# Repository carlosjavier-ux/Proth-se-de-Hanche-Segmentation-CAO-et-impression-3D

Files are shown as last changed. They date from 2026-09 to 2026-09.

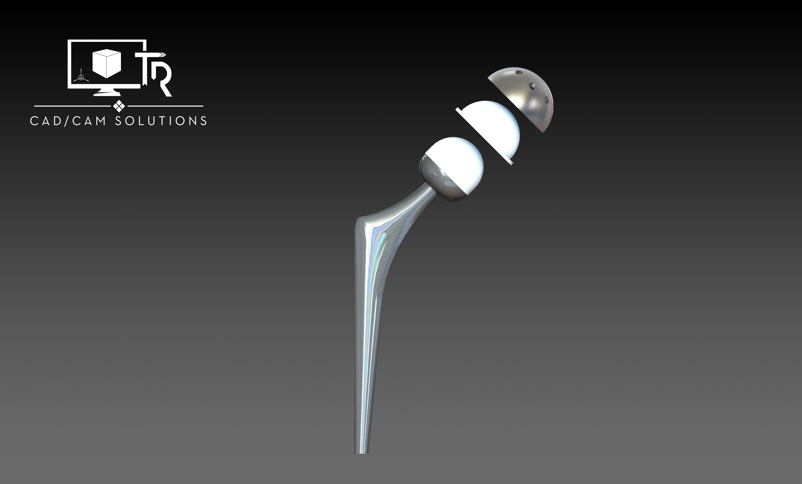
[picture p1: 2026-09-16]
Prothese_GRABCAD_NonModifie/hip1.png

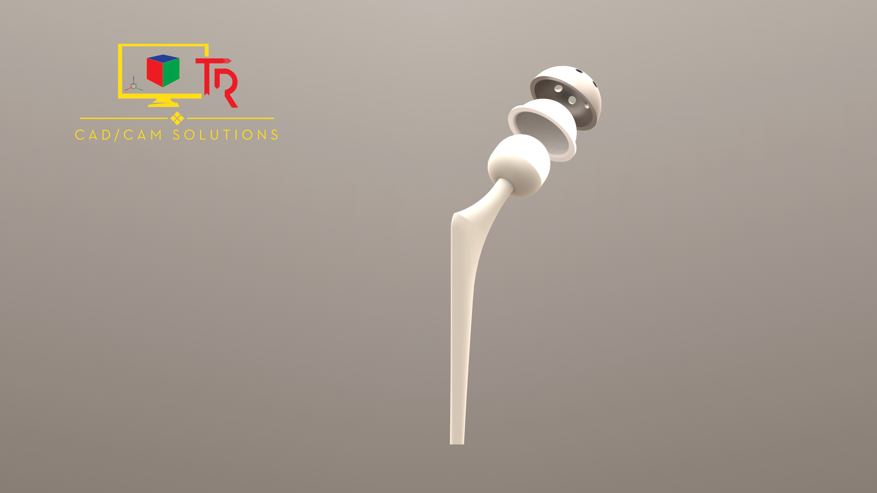
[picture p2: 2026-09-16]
Prothese_GRABCAD_NonModifie/hip.png

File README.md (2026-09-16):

# Pipeline d'Ingénierie Biomécanique : Prothèse de Hanche Personnalisée 




##  Description du Projet
Ce dépôt documente la chaîne numérique complète pour la conception et l'intégration d'une prothèse totale de hanche personnalisée, couvrant le flux de travail depuis l'acquisition anatomique jusqu'à la fabrication additive. L'objectif clinique principal de la modélisation est de restaurer le centre de rotation physiologique tout en évitant le phénomène de stress shielding, permettant de valider virtuellement l'implantation avant la production physique.

## ️ Chaîne Numérique (Pipeline Technique)

### 1. Segmentation et Traitement d'Images Médicales
L'extraction du modèle osseux fémoral à partir de l'IRM a été réalisée sous ITK-SNAP, en utilisant un processus de seuillage couplé à l'évolution d'un algorithme paramétrique Snake (Active Contours) pour garantir la précision anatomique.

### 2. Ingénierie Topologique et Nettoyage de Maillage
Le maillage brut a nécessité un post-traitement topologique intensif sous MeshLab et Meshmixer, assurant la transition vers une géométrie exploitable en CAO.
* Un algorithme de lissage de Taubin a été appliqué spécifiquement pour gommer l'effet d'escalier lié aux voxels sans altérer ni rétracter le volume global osseux, conservant ainsi les dimensions réelles.
* La structure a été optimisée par la suppression des arêtes "Non-Manifold" et une décimation quadratique réduisant le modèle à 100 000 faces, ce qui allège considérablement les calculs sans perte de détails critiques.

### 3. Simulation Biomécanique et Modélisation CAO (SolidWorks)
L'intégration du modèle d'implant (issu d'une base GrabCAD) a été paramétrée de manière biomécanique[cite: 3], en s'appuyant rigoureusement sur les centroïdes de l'anatomie native (points K, O et H).
* Ce référentiel de conception a permis de respecter strictement l'angle cervico-diaphysaire et l'offset fémoral, paramètres vitaux pour prévenir les luxations et conflits post-opératoires.
* Le lit d'implantation a été généré via des opérations booléennes avancées, notamment par une soustraction volumique (fonction Empreinte) et un enlèvement de matière balayé pour modéliser le tunnel exact d'insertion chirurgicale, validant virtuellement le passage physique de la tige fémorale.

### 4. Fabrication Additive (Impression 3D)
La validation physique de l'assemblage complet a été matérialisée grâce à une imprimante Bambu Lab, offrant une tolérance dimensionnelle optimale.
* Les modèles, incluant le fémur évidé et la prothèse préalablement scindée en deux parties pour éviter les surplombs complexes, ont été préparés pour garantir l'intégrité absolue des surfaces de contact, démontrant la viabilité de l'ensemble de la chaîne d'impression.

## Architecture du Dépôt

```text
├── FichiersSolidWorks/              # Assemblages (.sldasm) et pièces paramétriques (.sldprt) intégrant les coupes booléennes
├── FichiersEnSTL/                   # Maillages optimisés prêts pour le tranchage et l'impression 3D
├── Prothese_GRABCAD_NonModifie/     # Modèles CAO d'origine de l'implant avant adaptation biomécanique
└── IRM+Segmentation-Femur_1/        # Données sources isolées (fichiers .nii exclus du versioning pour optimisation)

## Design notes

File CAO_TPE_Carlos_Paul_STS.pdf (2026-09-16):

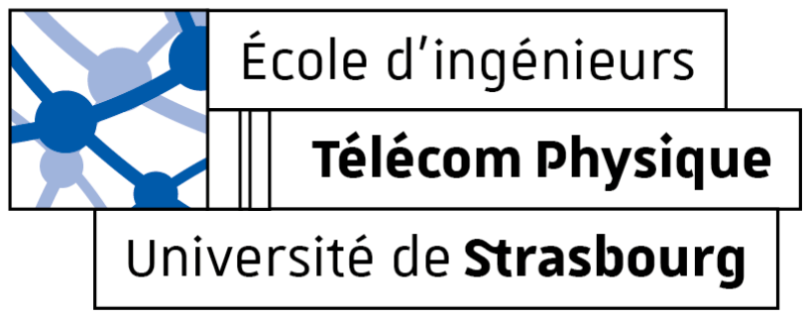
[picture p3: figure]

2025-26

# TPE STS

## Protocoles CAO

Carlos ALVAYERO VALIENTE
Paul GUIDONI-TARISSI

2A - Généraliste - STS

Ce document décrit le protocole complet, de la segmentation d'une acquisition IRM à l'impression 3D, intégrant les altérations anatomiques induites par l'implantation d'une prothèse.

Il regroupe donc les protocoles des logiciels suivants :

- ITK-SNAP
- MeshLab
- Meshmixer
- SolidWorks
©2026 Paul GUIDONI-TARISSI et Carlos ALVAYERO VALIENTE. Tous droits réservés. | 2

# ITK-SNAP

1. Préparation et Importation
- Ouvrez votre fichier IRM : File -> Open Main Image.
- Assurez-vous que le contraste est optimal pour distinguer l'os cortical (généralement noir en IRM) de la moelle et des tissus mous environnants.
2. Configuration de l'outil Snake
1. Sélectionnez l'outil Snake Tool dans la barre d'outils à gauche (icône ressemblant à un serpent ou une bulle).
2. Définissez la zone de travail (ROI) : Une boîte rouge apparaît. Ajustez-la dans les trois vues (axiale, sagittale, coronale) pour qu'elle englobe uniquement le fémur. Cela limite les calculs et évite que la segmentation ne "fuit" vers d'autres os.
3. Cliquez sur Segment 3D en bas à droite.
3. Étape de Prétraitement (Pre-segmentation)

C'est ici que vous déterminez ce qui la zone d’intéret et ce qui ne l'est pas.

- Mode de prétraitement : Choisissez généralement Thresholding (Seuillage).
- Réglage des seuils : En IRM, l'os compact est sombre, mais l'intérieur (moelle) peut être clair. Vous devez ajuster les curseurs pour que le fémur apparaisse en blanc (fortes probabilités) et le reste en bleu/transparent.
- Note : Si l'os est plus sombre que les tissus, utilisez un seuil inversé ou le mode "Edge-based" (basé sur les contours) si les contrastes sont nets.
- Cliquez sur Next.
4. Initialisation des "Bulles"
- Vous devez maintenant placer des germes (seeds). Cliquez sur le fémur dans les différentes vues pour placer des petites bulles rouges.
- Placez-en plusieurs le long de la diaphyse et au niveau de la tête fémorale.
- Ces bulles vont "gonfler" pour remplir l'espace défini lors de l'étape précédente.
5. Évolution du Snake
- Dans l'onglet Evolution, ajustez les paramètres si nécessaire :
- Continuity force : Empêche le serpent de devenir trop irrégulier.
- Balloon force : Pousse les bulles à se dilater.
- Cliquez sur le bouton Play (flèche droite). Vous verrez les bulles s'étendre automatiquement pour épouser les formes de l'os.
©2026 Paul GUIDONI-TARISSI et Carlos ALVAYERO VALIENTE. Tous droits réservés. | 3

- Arrêtez l'évolution (Pause) avant que la segmentation ne dépasse les limites de l'os (phénomène de "fuite").
6. Finalisation et Retouches
- Une fois satisfait, cliquez sur Update pour transformer l'évolution en un label solide.
- Nettoyage manuel : Utilisez l'outil Adaptive Brush (Pinceau) pour corriger les petites erreurs, notamment au niveau des articulations où le logiciel peut confondre le fémur avec le tibia ou le bassin.
©2026 Paul GUIDONI-TARISSI et Carlos ALVAYERO VALIENTE. Tous droits réservés. | 4

# MeshLab

1. Importer le modèle

Ouvrez MeshLab et glissez-déposez le fichier .stl que vous avez exporté depuis ITK-SNAP.

### 2. Nettoyer les "bruits" flottants très fréquents en IRM

La segmentation attrape souvent des petits pixels isolés qui flottent autour de l'organe principal. Il faut les supprimer avant de lisser.

1. Allez dans le menu Filters > Cleaning and Repairing.
2. Cliquez sur Remove Isolated pieces (wrt Diameter).
3. Dans la fenêtre, le paramètre Max Diameter détermine la taille maximale des morceaux à supprimer. Laissez par défaut ou augmentez légèrement, cochez Remove unreferenced vertices, puis cliquez sur Apply.
4. Fermez la fenêtre. Tous les petits fragments flottants ont disparu.

### 3. Le Lissage (Gommer l'effet "escalier" des voxels)

C'est l'étape magique pour les fichiers médicaux. Nous allons utiliser un filtre spécifique qui lisse la surface sans pour autant faire rétrécir (dégonfler) votre modèle.

1. Allez dans Filters > Smoothing, Fairing and Deformation.
2. Sélectionnez Taubin Smooth (c'est le meilleur algorithme pour les données médicales).
3. Une fenêtre s'ouvre. Le paramètre important est Smoothing steps (Nombre d'étapes de lissage).
- Par défaut, il est sur 10. Changez-le pour 50 ou 100 pour commencer.
- J’ai changé de lambda pour 0.75 (dans mon cas d’un fémur).
4. Cliquez sur Apply. Observez votre modèle : il devrait perdre son aspect “escalier” pour devenir organique et lisse. S'il n'est pas assez lisse, cliquez sur Apply ou augmentez le nombre d'étapes.

### 4. Boucher les petits trous (Étanchéité)

Le lissage peut parfois révéler ou étirer de minuscules trous dans le maillage.

1. Allez dans Filters > Remeshing, Simplification and Reconstruction.
2. Sélectionnez Close Holes.
3. Dans Max size to be closed, laissez par défaut (cela bouchera les petits trous sans détruire la forme globale) et cliquez sur Apply.
©2026 Paul GUIDONI-TARISSI et Carlos ALVAYERO VALIENTE. Tous droits réservés. | 5

Si il y a une erreur :

Étape 4.1 : Supprimer les faces "Non-Manifold"

Nous allons demander au logiciel de détruire la géométrie impossible.

1. Allez dans le menu Filters > Cleaning and Repairing.
2. Cliquez sur Remove Faces from Non Manifold Edges.
3. Dans la petite fenêtre qui s'ouvre, cliquez sur Apply puis fermez-la. Note : Cette action va supprimer les mauvais triangles. Cela va potentiellement agrandir certains trous ou en créer de nouveaux, mais c'est exactement ce que l'on veut : obtenir des trous propres.

Étape 4.2 : (Recommandé) Gérer les faces croisées

Souvent, les problèmes non-manifold sont accompagnés de faces qui rentrent les unes dans les autres.

1. Allez dans Filters > Cleaning and Repairing.
2. Cliquez sur Select Self Intersecting Faces (Sélectionner les faces qui s'auto-intersectent), puis sur Apply et fermez.
3. Si certaines zones de votre modèle deviennent rouges, ce sont les faces corrompues.
4. Pour les supprimer, regardez dans la barre d'icônes tout en haut de MeshLab. Cherchez l'icône représentant un triangle jaune avec une petite croix rouge (le bouton s'appelle "Delete the current set of selected faces" si vous laissez la souris dessus). Cliquez dessus.

Étape 4.3 : Relancer le bouchage de trous

Maintenant que les bords de vos trous sont propres et "manifold", l'outil va fonctionner.

1. Allez dans Filters > Remeshing, Simplification and Reconstruction.
2. Sélectionnez Close Holes.
3. Cliquez sur Apply.

### 5. La Décimation (Alléger le fichier)

Les modèles segmentés par IRM font souvent des millions de triangles. Si vous l'envoyez tel quel dans un logiciel de tranchage d'impression 3D, votre ordinateur risque de planter. Il faut le compresser.

1. Allez dans Filters > Remeshing, Simplification and Reconstruction.
2. Cliquez sur Simplification: Quadric Edge Collapse Decimation.
©2026 Paul GUIDONI-TARISSI et Carlos ALVAYERO VALIENTE. Tous droits réservés. | 6

3. Repérez la ligne Target number of faces (Nombre de faces cible).
- Remplacez le chiffre par 100000 (100 000 triangles) ou 50000. C'est un excellent compromis entre qualité des détails et légèreté du fichier.
4. Assurez-vous que les cases Preserve Boundary of the mesh et Preserve Normal sont cochées.
5. Cliquez sur Apply. L'opération peut prendre quelques dizaines de secondes selon la puissance de votre ordinateur.

### 6. Exporter le résultat final

Votre modèle est maintenant lisse, propre et léger.

1. Allez dans File > Export Mesh As...
2. Nommez votre fichier (par exemple Modele_IRM_Lisse.stl).
3. Dans la fenêtre des paramètres d'exportation, décochez "Color" et assurez-vous de choisir le format Binary.
4. Cliquez sur OK.
©2026 Paul GUIDONI-TARISSI et Carlos ALVAYERO VALIENTE. Tous droits réservés. | 7

# Meshmixer

Méthode pour reboucher les trous pour fermer le contour

Le logiciel va détecter le trou béant et le refermer :

1. Importez votre fichier STL dans Meshmixer.
2. Dans le menu de gauche, cliquez sur Analysis, puis sur Inspector.
3. Meshmixer va analyser le modèle. Le grand trou à la base de votre os sera désigné par une sphère (ou une bulle) de couleur, généralement bleue ou magenta, reliée par un trait au bord du trou.
4. Attention : Avant de cliquer sur cette bulle, regardez le petit menu en haut à gauche. Cherchez la ligne Hole Fill Mode (Mode de remplissage). Par défaut, il est sur Flat Fill (Remplissage plat). Pour un os, changez-le en Smooth Fill (Remplissage lisse). Cela permettra à la matière de s'arrondir naturellement au lieu de faire une coupe parfaitement plate.
5. Cliquez sur la petite bulle colorée qui pointe vers votre trou. Le trou va se boucher.
6. Cliquez sur Done en haut à gauche pour valider.

Couper un objet en deux

Étape 1 : Activer l'outil de coupe

1. Importez votre fichier STL dans Meshmixer.
2. Dans le menu principal à gauche, cliquez sur Edit.
3. Cliquez sur l'outil Plane Cut (Coupe par plan).

Étape 2 : Positionner la coupe

Un grand plan transparent quadrillé apparaît à travers votre objet, accompagné d'un manipulateur au centre (des flèches et des arcs de cercle).

- Cliquez et tirez sur les flèches pour déplacer le plan de haut en bas ou de gauche à droite.
- Cliquez et tirez sur les arcs de cercle pour incliner le plan.
- Astuce : Si vous voulez une rotation parfaite (par exemple exactement 90°), maintenez la touche Maj (Shift) enfoncée pendant que vous tournez l'arc de cercle, cela va cranter la rotation par paliers.
©2026 Paul GUIDONI-TARISSI et Carlos ALVAYERO VALIENTE. Tous droits réservés. | 8

Étape 3 : Le réglage crucial (Garder les deux moitiés)

Attention : Par défaut, Meshmixer va supprimer l'une des deux moitiés (la partie transparente). Si vous voulez garder les deux morceaux, il faut changer un réglage :

1. Regardez la petite fenêtre d'options "Plane Cut" en haut à gauche.
2. Cherchez la ligne Cut Type (Type de coupe). Par défaut, il est sur Cut (Discard Half).
3. Cliquez dessus et changez-le pour Slice (Keep Both). Votre objet redevient entièrement opaque, avec une ligne rouge au milieu.
4. Juste en dessous, assurez-vous que le Fill Type (Type de remplissage) est sur Remeshed Fill. Cela permet à Meshmixer de boucher les trous créés par la coupe pour que les deux morceaux soient bien étanches.
5. Cliquez sur Accept.

Étape 4 : Séparer les deux morceaux

La pièce est maintenant coupée et rebouchée, mais pour le moment, Meshmixer considère toujours qu'il s'agit d'un seul et unique fichier contenant deux morceaux collés. Il faut les séparer.

1. Retournez dans le menu Edit à gauche.
2. Cliquez sur Separate Shells (Séparer les coques).
3. Une petite fenêtre flottante appelée Object Browser apparaît. Vous y verrez maintenant deux lignes (vos deux morceaux), au lieu d'une seule.

Étape 5 : Exporter chaque morceau

Pour imprimer vos pièces, il faut les exporter en deux fichiers STL distincts.

1. Dans la fenêtre Object Browser, cliquez sur le premier morceau (il va se mettre en surbrillance blanche dans la zone 3D). L'autre morceau va devenir grisé ou invisible, c'est normal avec l'icône de l'œil.
2. Allez dans File > Export.
3. Choisissez le format STL Binary Format et nommez-le.
4. Retournez dans l'Object Browser, cliquez sur le deuxième morceau et répétez l'opération File > Export.
©2026 Paul GUIDONI-TARISSI et Carlos ALVAYERO VALIENTE. Tous droits réservés. | 9

# SolidWork

Ouvrir un fichier .stl :

Dans SolidWorks, aller dans ouvrir en haut à gauche, en sélectionnant le fichier aller dans option et cocher corps volumique, dans importer en tant que.

Méthode : dans un fichier Assemblage (.sldasm)

1. Éditer la pièce cible : Dans l'arbre de création à gauche, cliquez sur le nom de votre Fémur et sélectionnez Éditer la pièce (l'icône avec une petite page et un crayon bleu).
2. Lancer l'outil : Allez dans le menu tout en haut : Insertion > Fonctions de moule > Empreinte (Cavity).
3. Sélectionner l'outil de coupe : Dans le menu de gauche qui vient de s'ouvrir, cliquez dans la case bleue "Composants de conception", puis cliquez sur votre Prothèse dans la zone graphique 3D.
4. Valider : Cliquez sur la coche verte.
5. Quitter l'édition : Cliquez sur le bouton de confirmation d'édition (la petite icône bleue en haut à droite de la zone graphique) pour repasser en mode Assemblage normal.
6. Vérification : Si vous cachez la prothèse (clic droit > Cacher), vous verrez que votre fémur est maintenant parfaitement évidé avec la forme exacte de l'insert.

Méthode : Prévoir insertion, exemple prothèse fémur

Étape 1 : Dessiner la trajectoire de sortie/entrée

Le logiciel a besoin d'une ligne droite pour savoir dans quelle direction et sur quelle distance vous allez tirer la prothèse pour la sortir du fémur.

1. Ouvrez votre fichier fémur (assurez-vous d'avoir la prothèse et le fémur dans le même fichier .sldprt sous forme de "Corps volumiques", ou soyez en mode "Éditer la pièce" dans votre assemblage avec la prothèse visible).
2. Sélectionnez un plan (Face ou Droite) qui traverse le milieu de votre fémur et de la prothèse.
3. Cliquez sur Esquisse.
4. Dessinez une simple Ligne droite. Faites-la partir du centre de la prothèse et pointer vers l'extérieur (vers le haut, dans l'axe d'extraction naturel que le chirurgien utiliserait).
5. Assurez-vous que la ligne soit assez longue pour que la prothèse sorte complètement de l'os.
6. Validez et quittez l'esquisse.
©2026 Paul GUIDONI-TARISSI et Carlos ALVAYERO VALIENTE. Tous droits réservés. | 10

Étape 2 : Le balayage volumique (Le "tunnel" d'insertion)

On va utiliser la prothèse comme un outil qu'on va tirer le long de la ligne.

1. Allez dans l'onglet Fonctions et cliquez sur Enlèvement de matière balayé (l'icône avec un tuyau coupé).
2. Dans le menu de gauche, cochez impérativement l'option Profil de corps volumique (Solid Profile) au lieu de "Profil d'esquisse".
3. Dans la case bleue (Corps d'outil), cliquez sur votre Prothèse.
4. Dans la case rose (Trajectoire), cliquez sur la Ligne droite que vous venez de dessiner.
5. Regardez l'aperçu jaune : SolidWorks va vous montrer le "tunnel" généré par le mouvement de la prothèse.
6. Cliquez sur la coche verte pour valider.
©2026 Paul GUIDONI-TARISSI et Carlos ALVAYERO VALIENTE. Tous droits réservés. | 11

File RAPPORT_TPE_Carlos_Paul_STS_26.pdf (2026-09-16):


2025-26

# TPE STS

## Prothèse de Hanche : Segmentation, CAO et impression 3D

Carlos ALVAYERO VALIENTE
Paul GUIDONI-TARISSI

2A - Généraliste - STS

# Table des matières

### 2. Acquisition et Traitement du Modèle Anatomique (Workflow Numérique)4

2.2. Nettoyage et Optimisation du Maillage (MeshLab et Meshmixer).....4
©2026 Paul GUIDONI-TARISSI et Carlos ALVAYERO VALIENTE. Tous droits réservés. | 2

## Introduction

L’arthroplastie totale de hanche (PTH) est l’une des interventions chirurgicales les plus pratiquées pour traiter des pathologies invalidantes telles que la coxarthrose ou l’ostéonécrose aseptique. Toutefois, la réussite clinique dépend d'un compromis complexe entre la géométrie de la prothèse et la précision de l'acte chirurgical. L'émergence de la chaîne numérique permet aujourd'hui une personnalisation sans précédent.

L'objectif de ce projet est de simuler l'intégralité du processus de conception d'un segment anatomique : de l'acquisition des données anatomiques par IRM à la réalisation d'un prototype physique par impression 3D. À travers l'étude d'un modèle de fémur, nous détaillons les étapes de segmentation d'images, de nettoyage de maillage, de positionnement biomécanique en CAO, et enfin d'opérations booléennes permettant de simuler l'implantation chirurgicale.

©2026 Paul GUIDONI-TARISSI et Carlos ALVAYERO VALIENTE. Tous droits réservés. | 3

## 1. Contexte Clinique et Justification Biomécanique

La conception d'une prothèse repose sur des impératifs de transfert de charges dictés par la pathologie du patient. L'intervention vise à pallier des défaillances telles que la coxarthrose (usure du cartilage représentant 80 % des indications) ou l'ostéonécrose aseptique (effondrement structurel de l'os par ischémie).

Pour répondre à ces contraintes, l'implant fémoral (tige) doit assurer une stabilité rotationnelle et éviter le phénomène de stress shielding (absorption excessive des contraintes par l'implant, menant à l'atrophie osseuse). Le défi de notre modélisation est donc d'intégrer virtuellement une prothèse tout en respectant l'anatomie native du patient.

Pour une analyse approfondie des données cliniques, chirurgicales et des sources consultées, il convient de se référer au document de bibliographie joint à ce projet.

©2026 Paul GUIDONI-TARISSI et Carlos ALVAYERO VALIENTE. Tous droits réservés. | 4

## 2. Acquisition et Traitement du Modèle Anatomique (Workflow Numérique)

La première phase de notre chaîne numérique consiste à extraire un modèle 3D exploitable à partir de données d'imagerie médicale brutes.

### 2.1. Segmentation des données IRM

Nous nous sommes basés sur une banque d'images IRM (IRM-Femur_1 ) fournie par M. Baptiste Gomes. La segmentation a été réalisée sous le logiciel ITK-SNAP pour isoler le tissu osseux fémoral des tissus mous environnants, générant ainsi un premier maillage de surface (fichier Carlos&Paul.nii ) exporté au format STL.

### 2.2. Nettoyage et Optimisation du Maillage (MeshLab et Meshmixer)

Le maillage brut issu de l'IRM présentait un effet "escalier" (lié à la taille des voxels) et de nombreux artefacts géométriques, le rendant inexploitable pour des opérations CAO ultérieures. Un post-traitement rigoureux a été appliqué sous MeshLab et Meshmixer :

- Suppression du bruit et réparation : Élimination des "bruits" flottants (fragments isolés) via le filtre de nettoyage de MeshLab. Les faces "Non-Manifold" et les auto-intersections ont été supprimées pour garantir l'intégrité topologique du modèle.
- Lissage de surface (Smoothing) : Application de l'algorithme Taubin Smooth (avec 50 à 100 étapes et un λ de 0.75). Cet algorithme spécifique aux données médicales permet de lisser la surface sans provoquer de rétractation (rétrécissement) du volume global.
- Rebouchage et Étanchéité : Les trous générés par la coupe des extrémités ont été rebouchés sous Meshmixer en utilisant l'option Smooth Fill, permettant de conserver une courbure organique.
- Décimation : Pour permettre la manipulation sous SolidWorks, le maillage a été compressé à environ 100 000 faces via l'outil Quadric Edge Collapse Decimation, tout en préservant les normales et les frontières géométriques.
©2026 Paul GUIDONI-TARISSI et Carlos ALVAYERO VALIENTE. Tous droits réservés. | 5

## 3. Positionnement Virtuel et Opérations de CAO (SolidWorks)

Un modèle 3D de prothèse de hanche a été sourcé (GrabCad) puis importé dans l'environnement d'assemblage de SolidWorks aux côtés du fémur optimisé.

### 3.1. Référentiel et Positionnement Biomécanique

Le placement de l'implant ne se fait pas arbitrairement. Nous nous sommes appuyés sur les règles géométriques définies dans la thèse d'Anthony Viste. L'orientation fémorale a été construite autour de trois points centroïdes critiques :

- Le point K (centre du genou).
- Le point O (centre de la base du col fémoral).
- Le point H (centre de la tête fémorale).

L'alignement de la tige et du col a nécessité le respect de l'angle cervico-diaphysaire natif (ACD) et de l'offset fémoral. La prothèse a été orientée de manière à simuler le rétablissement du centre de rotation (COR) physiologique pour prévenir tout conflit mécanique post-opératoire.

### 3.2. Opérations Booléennes et Simulation d'Implantation

Une fois le positionnement validé, il a fallu évider le fémur pour modéliser le lit d'implantation. Nous avons procédé en deux étapes sous SolidWorks :

1. L'Empreinte (Opération booléenne statique) : Utilisation de la fonction "Empreinte" (Cavity) en mode assemblage pour soustraire le volume exact de la tige fémorale du corps volumique du fémur.
2. Le chemin d'insertion (Balayage cinématique) : Lors de la chirurgie, la prothèse n'apparaît pas par magie dans l'os ; elle y est insérée. Nous avons modélisé ce "tunnel" d'insertion en dessinant une esquisse de la trajectoire d'extraction (alignée sur l'axe du canal médullaire). Un "Enlèvement de matière balayé" utilisant le corps volumique de la prothèse comme outil de coupe a ensuite été réalisé.
©2026 Paul GUIDONI-TARISSI et Carlos ALVAYERO VALIENTE. Tous droits réservés. | 6

## 4. Préparation à la Fabrication Additive (Impression 3D)

La dernière phase du projet a consisté à générer les fichiers finaux pour la concrétisation physique. L’impression des différents composants a été réalisée sur une machine Bambu Lab, choisie pour sa haute précision dimensionnelle et sa gestion optimisée des supports, garantissant le respect des tolérances géométriques de l'assemblage. Les modèles ont été scindés ou adaptés pour optimiser la qualité d'impression. L'arborescence des livrables finaux se décline ainsi :

- FemurCoupeEvide_FINAL_imp : Le fémur imprimé, coupé au niveau du col, présentant le canal d'insertion modélisé.
- TeteFemorale_FINAL_imp : La tête fémorale native, correspondant à la résection osseuse effectuée par le chirurgien.
- ProtheseEntiere_FINAL : Imprimée en deux parties (PART1 et PART2) pour éviter les surplombs complexes et garantir l'intégrité des surfaces d'assemblage.
- Les | composants | acétabulaires | : | Acetabular_FINAL_imp (cupule) | et
PlasticLiner_FINAL_imp (insert).
©2026 Paul GUIDONI-TARISSI et Carlos ALVAYERO VALIENTE. Tous droits réservés. | 7

## Conclusion

Ce projet transversal nous a permis d'appréhender la complexité du développement d'implants orthopédiques. En maîtrisant la transition entre l'imagerie médicale (ITK-SNAP), la réparation topologique (MeshLab/Meshmixer) et la conception mécanique paramétrique (SolidWorks), nous avons validé une méthodologie robuste de positionnement virtuel. Cette chaîne numérique, conclue par l'impression 3D des composants, illustre comment l'ingénierie moderne répond aux défis cliniques de la chirurgie personnalisée.

©2026 Paul GUIDONI-TARISSI et Carlos ALVAYERO VALIENTE. Tous droits réservés. | 8

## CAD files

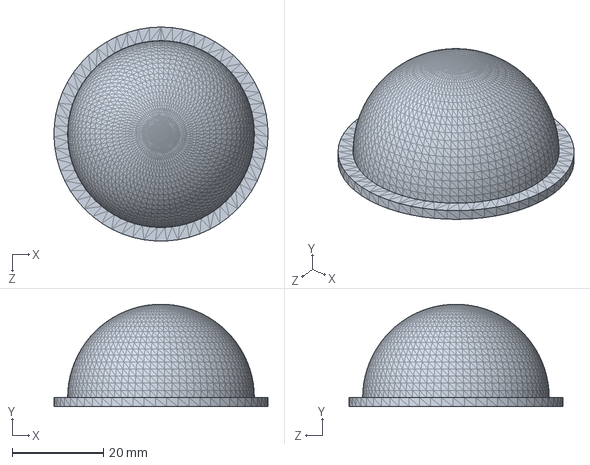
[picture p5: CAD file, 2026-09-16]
FichiersSolidWorks/PlasticLiner_FINAL_imp.SLDPRT
47.0 x 22.5 x 47.0 mm

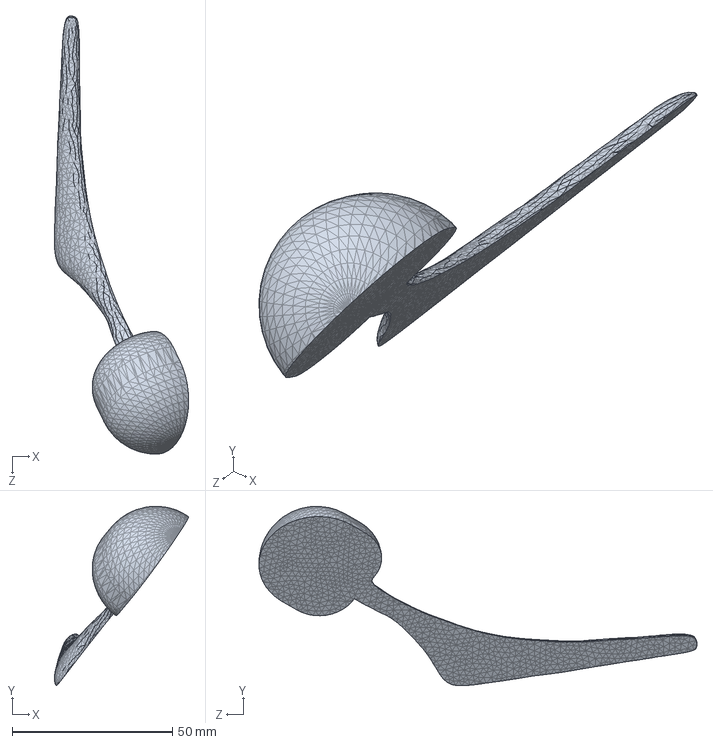
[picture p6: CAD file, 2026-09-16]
FichiersSolidWorks/ProthesePART2_FINAL_imp.SLDPRT
41.9 x 55.9 x 136.6 mm

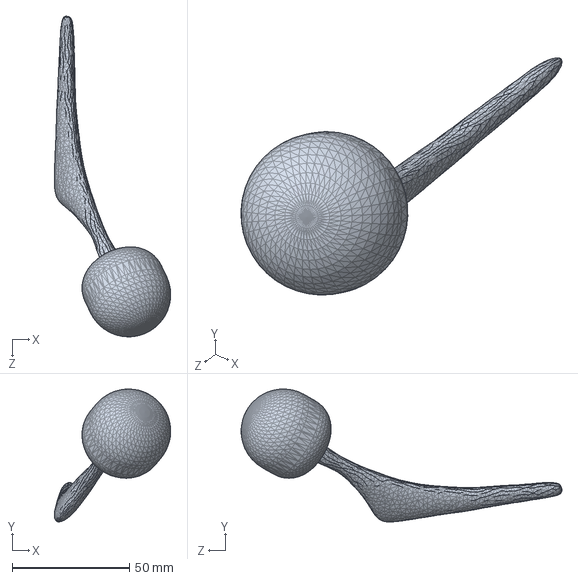
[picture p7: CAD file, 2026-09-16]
FichiersSolidWorks/ProtheseEntiere_FINAL.SLDPRT
49.6 x 56.7 x 136.6 mm

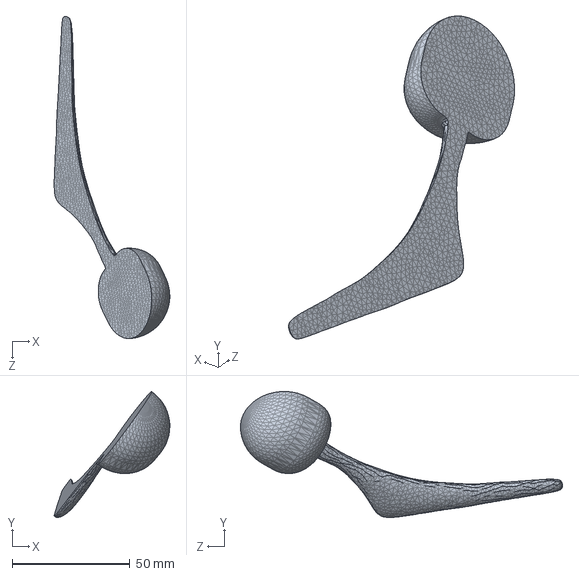
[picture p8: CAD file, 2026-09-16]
FichiersSolidWorks/ProthesePART1_FINAL_imp.SLDPRT
49.1 x 53.5 x 136.6 mm

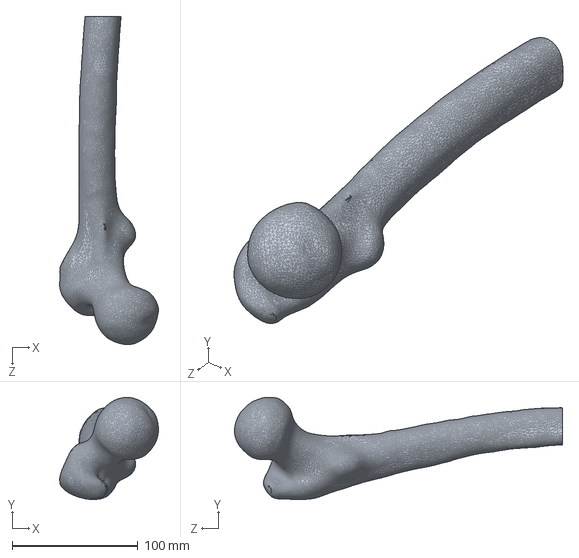
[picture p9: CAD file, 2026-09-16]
FichiersSolidWorks/FemurEntier_FINAL.SLDPRT
78.6 x 81.2 x 260.8 mm

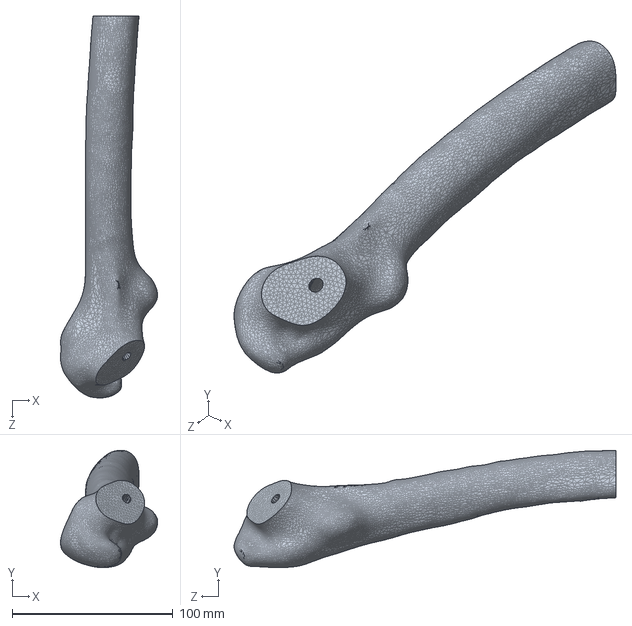
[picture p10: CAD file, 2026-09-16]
FichiersSolidWorks/FemurTRACEconstruction_FINAL.SLDPRT
60.5 x 73.0 x 237.8 mm

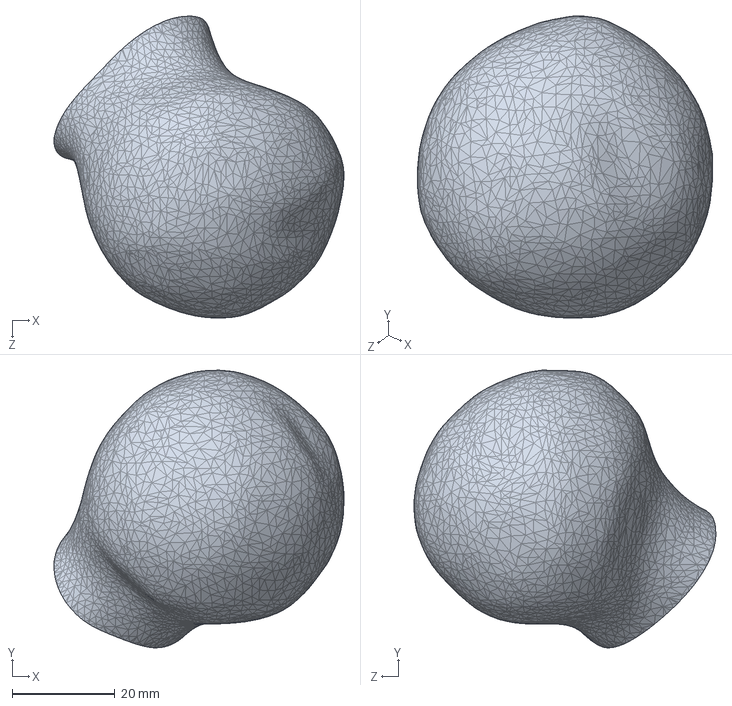
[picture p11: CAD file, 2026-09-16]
FichiersSolidWorks/TeteFemorale_FINAL_imp.SLDPRT
56.5 x 54.1 x 58.9 mm

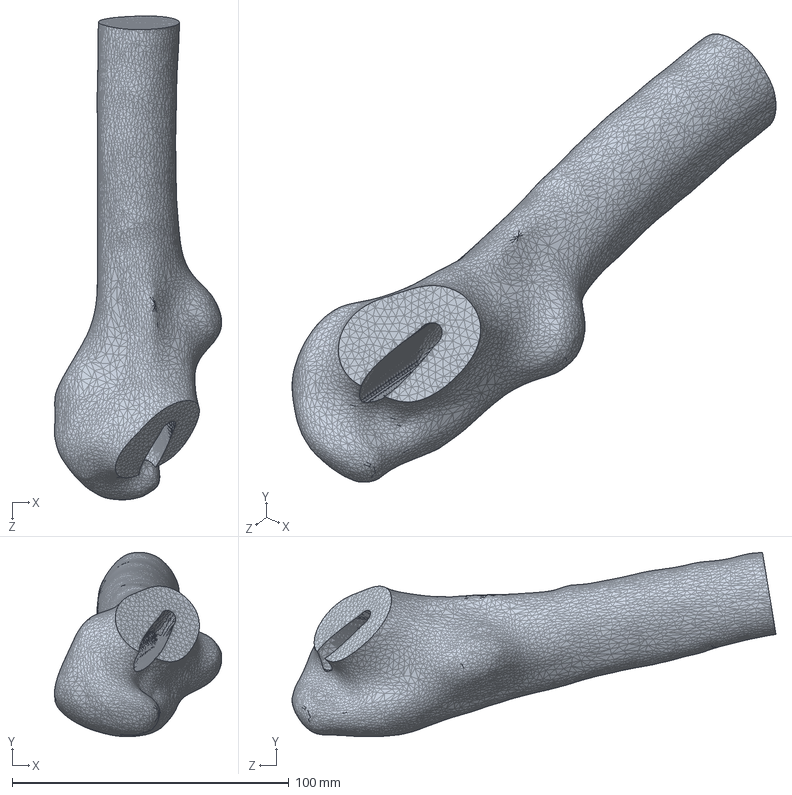
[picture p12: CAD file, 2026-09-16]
FichiersSolidWorks/FemurCoupeEvide_FINAL_imp.SLDPRT
60.5 x 66.6 x 174.8 mm

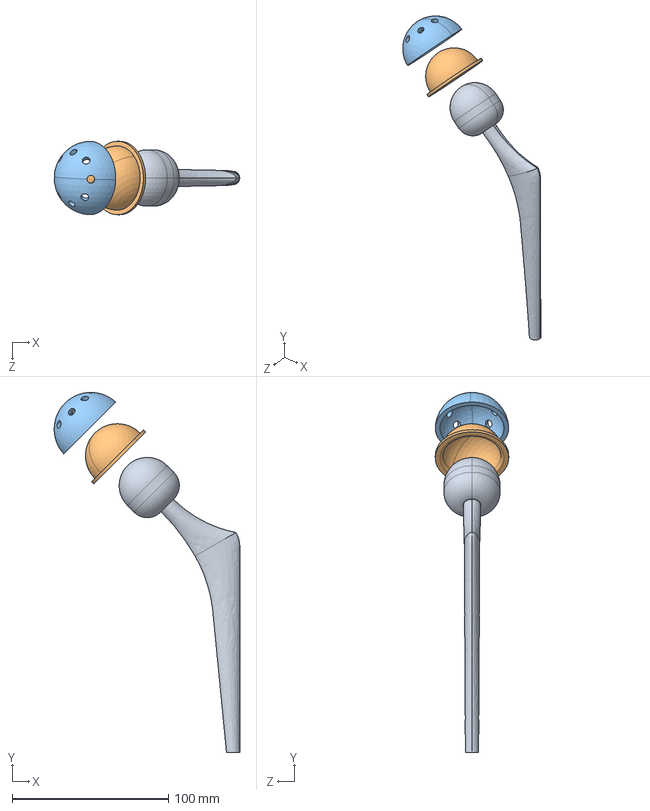
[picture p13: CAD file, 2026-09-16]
Prothese_GRABCAD_NonModifie/Assem1.STEP
118.6 x 230.2 x 47.0 mm
hip proethesis
plastic liner
acetabular

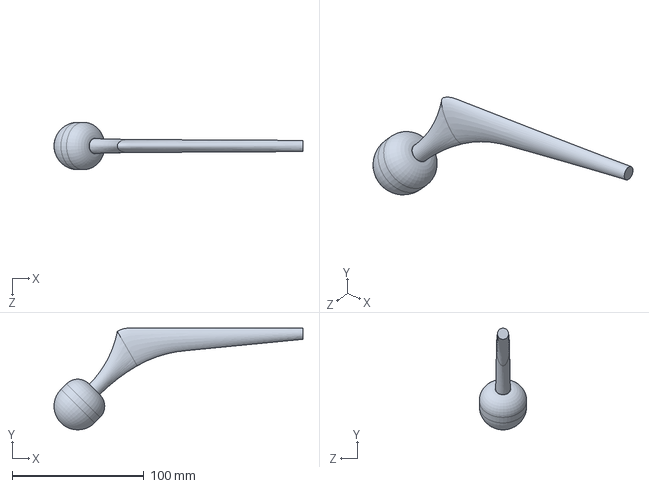
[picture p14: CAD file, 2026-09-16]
Prothese_GRABCAD_NonModifie/hip proethesis.SLDPRT
188.7 x 77.1 x 35.9 mm

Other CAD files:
FichiersSolidWorks/Acetabular_FINAL_imp.SLDPRT
Prothese_GRABCAD_NonModifie/acetabular.SLDPRT
Prothese_GRABCAD_NonModifie/plastic liner.SLDPRT
Prothese_GRABCAD_NonModifie/Assem1.IGS
Prothese_GRABCAD_NonModifie/Assem1.SLDASM
Prothese_GRABCAD_NonModifie/Assem1.x_t

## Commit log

2026-09-16 feat: scripts de segmentation et structure du projet CAO
    [Acetabular_FINAL_imp.SLDPRT, Assem1.IGS, Assem1.SLDASM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]
2026-09-16 docs: mise a jour complete du README avec la pipeline biomecanique et CAO detaille
